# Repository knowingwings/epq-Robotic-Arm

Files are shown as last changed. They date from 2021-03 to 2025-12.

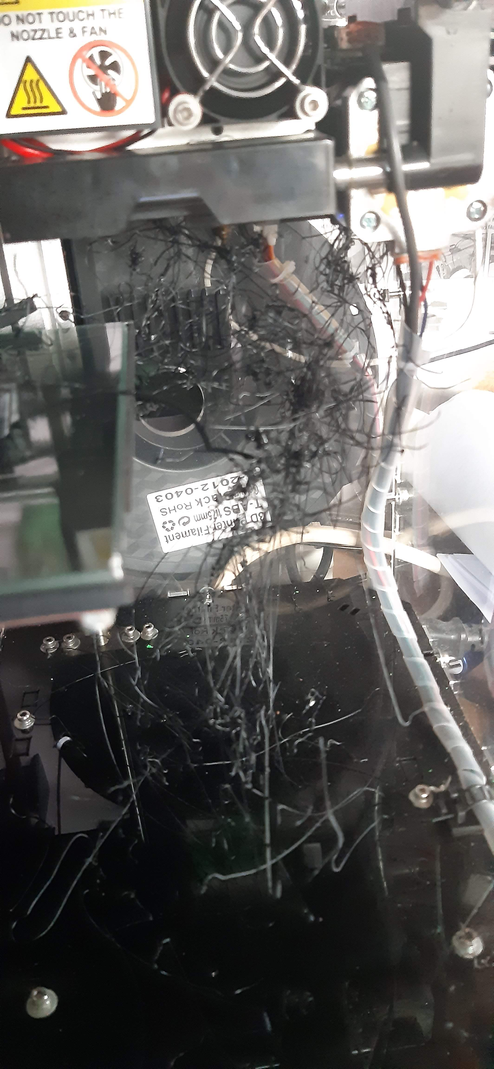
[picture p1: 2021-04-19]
Testing_Documentation/Testing_Evidence/20210409_082313.jpg

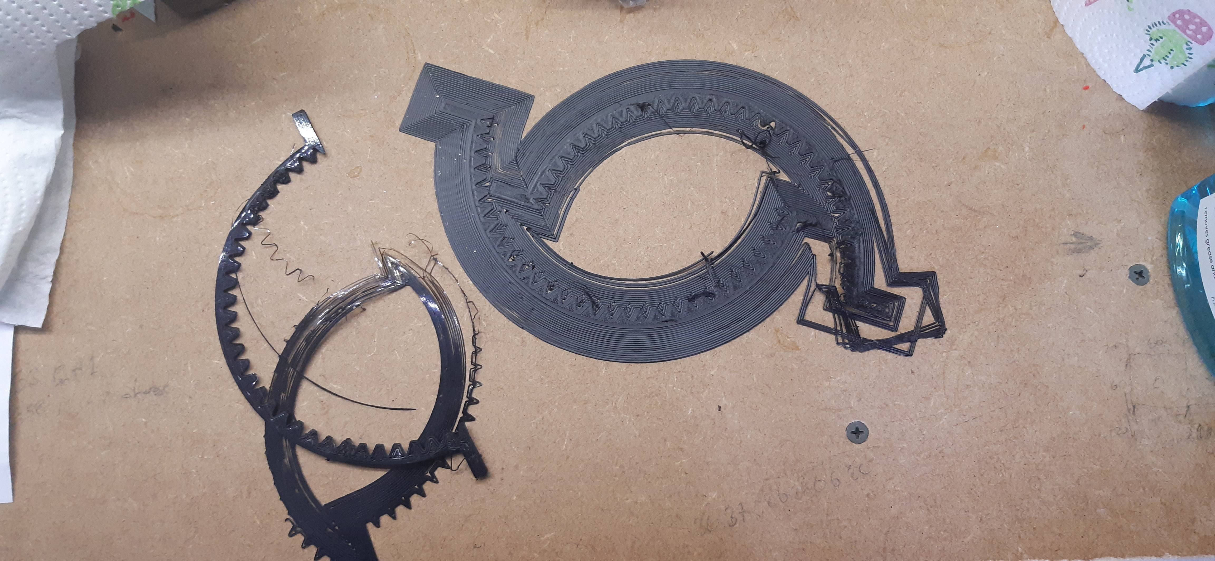
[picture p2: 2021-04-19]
Testing_Documentation/Testing_Evidence/20210409_155532.jpg

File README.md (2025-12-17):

# 6-DOF Robotic Arm with Custom Strain Wave Gearing

A-Level Extended Project Qualification (EPQ) - Grade: A*

## Project Overview

This project involved the complete design and manufacture of a 6 degree-of-freedom robotic manipulator from first principles. Conducted at Elizabeth College, the arm features custom-designed strain wave (harmonic drive) gearing for high torque density and backlash-free motion.

**Key achievements:**
- Full kinematic chain design with 6 DOF
- Custom strain wave gearboxes designed and 3D printed
- Four major design iterations (Mk1 through Mk4.2) refining the design
- Arduino-based motion control with serial communication
- Complete CAD modelling in Fusion 360
- Comprehensive research into industrial robotic arm design

**Project duration:** September 2020 - April 2022 (500 days actual vs 210 days planned)

**Institution:** Elizabeth College
**Candidate:** Thomas William Le Huray

## Technical Specifications

### Mechanical Design

**Degrees of Freedom:** 6 (base rotation, shoulder, elbow, wrist pitch, wrist roll, gripper)

**Actuation:** NEMA 17 stepper motors (17HS16-2004 and 17HS4401S models)

**Gear Reduction:** ~100:1 through custom strain wave gearing

**Payload Capacity:** <0.8 kg (designed for light manipulation tasks such as 3D printer print removal)

**Materials:**
- PLA (3D printed structural components)
- Recycled aluminium arm pieces (Mk1-Mk3, from scrapped screen soldering machine)
- Custom 3D printed components (Mk4)
- Steel hardware (fasteners, bearings)

### Harmonic Drive Design

One of the key innovations in this project was the design and manufacture of custom strain wave gearboxes inspired by industrial Harmonic Drive SE units:

**Design features:**
- Wave generator (elliptical input)
- Flexspline (flexible outer gear)
- Circular spline (rigid internal gear)
- Modified output design for 3D printing (uses rigid internal gear as output rather than flexspline)
- ~100:1 reduction ratio
- Zero backlash operation
- Compact form factor

**Design inspiration:**
- 3D Printed Life's harmonic drive designs
- Levi Janssen's timing belt-based harmonic drives
- Industrial Vika-350 robotic arm
- Chris Annin's AR4 open-source arm

**Iterations:** Multiple design revisions (v1 to v15) optimising:
- Tooth profile for load capacity
- Flexspline wall thickness for flexibility
- Material selection for durability (PLA)
- Assembly tolerances for 3D printing

## Design Evolution

### Mk1: Initial Proof-of-Concept
- Used recycled metal arm pieces from Offshore Electronics work experience
- Bespoke components for each joint
- Too complex to manufacture with 3D printing
- Identified need for component standardisation

### Mk2: Shared Components
- Increased number of shared components
- Lighter design than Mk1
- First functional harmonic drive prototypes
- Still too heavy for the motors and reducers

### Mk3: Further Weight Reduction
- Further increased shared components
- Improved harmonic drive design
- Isometric sketches preceded CAD work
- Lower axis drives proved too weak to lift the arm
- Metal arm components still too heavy

### Mk4: Complete Redesign (Final Version)
**Mk4.1:**
- Complete redesign from scratch
- All components 3D printed (no recycled metal)
- Initial version too large and cumbersome
- Some parts didn't work as intended

**Mk4.2 (Final):**
- Reduced size by 100mm
- Fixed mechanical issues from Mk4.1
- Well thought-out design incorporating lessons from all previous versions
- Culmination of improved CAD and 3D printing skills

## Control System

### Hardware
- **Microcontroller:** Arduino
- **Motors:** NEMA 17 stepper motors (17HS16-2004, 17HS4401S)
- **Motor Drivers:** A4988 stepper drivers
- **Control Interface:** Raspberry Pi (planned) for remote access via Python

### Software
- **Motor Control:** AccelStepper library for Arduino
- **Language:** C++ (Arduino), Python (Raspberry Pi interface planned)
- **Communication:** Serial communication protocol
  - Commands specify: axis, number of steps, direction
- **Interface:** Python script (via pySerial) for remote control

### Control Architecture
Arduino receives commands via serial input → Interprets axis and step commands → Controls stepper motors via AccelStepper → Enables remote access through Raspberry Pi

## Manufacturing Challenges

### 3D Printing Issues

**Original Printer (PrintRite Colido 2.0 Plus):**
- Stopped functioning correctly during Mk3 testing
- Resulted in failed prints and project delays

**Replacement Printer (Voxelab Aquila X2):**
- Ender 3 clone with additional features
- Successfully printed Axis 4, 5, and 6 of Mk4.1
- Developed heat break clogging issue
- Plastic melted in heat break causing repeated printer failures
- Unable to resolve despite multiple disassembly attempts
- Project pivoted to focus on CAD design refinement due to timeline constraints

## Research Foundation

Comprehensive research into:
- **Industrial Arms:** Vika-350, KUKA KR350
- **Open-Source Projects:** Annin AR4, Faze 4 Robotics Hand
- **Gear Reducers:** Harmonic drives, cycloidal drives, planetary gearboxes
- **Control Systems:** Inverse kinematics, stepper motor control
- **3D Printing:** Gear tooth design, support-free printing techniques

See Works Cited in documentation for complete bibliography.

## Project Management & Timeline

**Original Estimate:** 210 days
**Actual Duration:** 500 days
**Timeline Overrun:** 138%

**Key Learning:** Poor initial planning that didn't account for:
- Examination periods
- Holiday breaks
- General inability to work on project during school term
- Hardware failures (3D printer issues)

**Reflection:** More pessimistic timelines would have been more accurate. Future projects should account for realistic availability and potential setbacks.

## Repository Structure

```
epq-Robotic-Arm/
├── CAD-files/
│   ├── Harmonic Drive/        # Strain wave gearbox components
│   ├── Mk2+3/                 # Early prototype iterations
│   ├── Mk4/                   # Final design iteration (Mk4.1 and Mk4.2)
│   └── Test Components/       # Test pieces and prototypes
│
├── Program_Files/
│   ├── test_Files/            # Motor control tests
│   │   └── Arduino/           # Stepper motor test code (AccelStepper library)
│   └── (main control code)
│
├── Components_Files/          # Bill of materials, component specs
│
├── documentation/
│   ├── EPQ Report draft 2.docx    # Complete project report
│   ├── EPQ Gantt Chart.xlsx       # Project timeline (planned vs actual)
│   └── EPQ Shopping List.xlsx     # Component sourcing
│
└── Testing_Documentation/     # Test results and validation
```

## Results

**EPQ Grade:** A* (highest grade)

**Project Outcomes:**
- Functional 6-DOF robotic arm design (Mk4.2)
- Custom harmonic drive gearboxes that achieved zero backlash
- Complete documentation and testing methodology
- Well-developed CAD skills through iterative design process

**Intended Applications:**
- 3D printer print removal
- Light object manipulation
- Control software experimentation
- Educational demonstration of robotic principles

## Key Learnings

This project provided hands-on experience in:

**Mechanical Engineering:**
- Kinematic chain design
- Custom gear design (strain wave gearing)
- Load analysis and structural design
- Tolerance analysis for 3D printed assemblies
- Iterative prototyping methodology
- Design optimisation through multiple iterations

**Software Engineering:**
- Arduino programming in C++
- Real-time motor control
- Serial communication protocols
- Library integration (AccelStepper)

**Systems Integration:**
- Electromechanical system design
- Power distribution
- Motor driver configuration
- Assembly and calibration procedures

**Project Management:**
- Timeline estimation and planning
- Adapting to setbacks and hardware failures
- Resource management
- Documentation practices

## Skills Demonstrated

- **CAD Modelling:** Fusion 360 (complex assemblies, gear design)
- **3D Printing:** Iterative prototyping, troubleshooting print failures
- **Mechanical Design:** Kinematics, gearing, structural analysis
- **Embedded Programming:** Arduino, C++
- **Control Systems:** Stepper motor control, serial communication
- **Research:** Comprehensive literature review and evaluation
- **Problem-Solving:** Four major design iterations, adapting to constraints
- **Technical Writing:** Comprehensive project report and documentation

## Progression

This EPQ project was the foundation for my continued work in robotics:

**Academic Progression:**
- **2020-2022:** A-Level (Maths, Physics, Computer Science) - Elizabeth College
- **2022-2023:** BEng Mechatronics (First Class Honours) - University of Gloucestershire
- **2024-Present:** MSc Robotics and Autonomous Systems - University of Bath

**Research Development:**
- EPQ: Custom robotic arm with harmonic drives
- BEng: Decentralised control architectures for dual mobile manipulators
- MSc: Multi-robot coordination and distributed control systems

See my [GitHub profile](https://github.com/knowingwings) for current projects including:
- [Distributed Mobile Robots](https://github.com/knowingwings/distributed-mobile-robots) - ROS2 multi-robot coordination platform
- [Decentralised Mobile Manipulator](https://github.com/knowingwings/decentralized-mobile-manipulator) - GPU-accelerated coordination algorithms

## Files & Documentation

**Key Files:**
- `documentation/EPQ Report draft 2.docx` - Complete project report
- `documentation/EPQ Gantt Chart.xlsx` - Timeline (planned vs actual)
- `CAD-files/Mk4/` - Final design CAD files (Fusion 360)
- `CAD-files/Harmonic Drive/` - Strain wave gearbox designs (v1-v15)
- `Program_Files/test_Files/Arduino/` - Motor control test code

**Note:** This was one of my first major engineering projects completed at age 16-18. The code and documentation reflect my skills at A-Level. For more recent work, see my university projects and current research.

## Acknowledgements

- Elizabeth College for supervision and support
- Offshore Electronics for work experience and recycled components (Mk1-Mk3)
- Open-source community for inspiration (Annin Robotics, 3D Printed Life, Levi Janssen)

## Licence

This project was completed as part of A-Level coursework. Code and designs provided for educational purposes.

## Author

**Thomas William Le Huray**
- Completed: April 2022 (A-Level Year 13)
- Grade: A* EPQ
- Institution: Elizabeth College
- Current: MSc Robotics @ University of Bath

---

*This repository documents my first significant robotics project at age 16-18. Whilst the implementation reflects early-stage skills, the project demonstrates fundamental engineering problem-solving, iterative design methodology, and hands-on fabrication capabilities that have continued to develop through my degree programmes.*

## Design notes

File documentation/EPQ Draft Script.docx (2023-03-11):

EPQ Draft Script:

Title slide:

My epq is the design and manufacture of a robotic arm.

00 Contents:

In this presentation I’m going to take you through what my project was about; the research I did; my plan; prototypes mk1 – mk3; the actual prototyping; the final design; and the manufacturing of the arm.

Video Slide:

This is roughly the idea of what I wanted the arm to be like at the beginning and you will see the full evolution of my design through the presentation.

01 Overview:

I decided early in the process of brainstorming my EPQ that I wanted to make a robotic project. I had many ideas from a quadruped robot, like Spot from Boston Dynamics, to making my own drone. Eventually I landed on a robotic arm, the simplest of all my ideas. With that I had an overall goal and I needed to work out the details I decided that it needed upwards of 5 degrees of freedom, how much the arm can move around, and be able to lift about 0.8kg (800grams). With this I began my research.

02 Research:

There are many ways to find information about robotic applications, people’s personal blogs; forum posts; and of course, YouTube. As you can see from the chart most of my research came from YouTube, the algorithm obviously knowing me too well. Lots of my research was into 3D printed reducers and transmissions.

03 The Plan:

I originally planned for the project too only take me 5 and a half months: in reality it has taken me well over a year, with many breaks for exams, young enterprise, generally forgetting that I had to do the project. I documented what happened through a development journal, this ended up becoming incredibly long. At the end of April, I had a block out for mk1 and then put the project on hold for exams.

04 Mk1 – Mk3:

In June I picked the project back up after salvaging aluminium hinged pieces from a scrapped screen soldering machine, from my work experience at Offshore Electronics. Mk1 featured a mixture of different types of geared reducers, planetary gearboxes and harmonic drives. However, the arm contained many bespoke parts, and weighed far too much for it too lift itself. Mk2 was lighter and featured more common components to reduce the complexity of manufacturing. Even though there was many improvements from mk1 to mk2 there was still room for improvement as the arm was still very heavy and unable to meet the lifting goal I was aiming for. Mk3 improved on Mk2 by reducing the weight of the arm by roughly 10%, and featured component coverings that reduced the number of exposed parts. Now you might be wondering what a harmonic drive is.

05 How it works:

A harmonic drive is a type of reducers, they are also called Strain wave gearing. You might be wondering why the name harmonic drive, well that’s because it’s named after the company that manufactured the first series of strain wave gearing, from Germany called Harmonic Drive SE. On the right you can see my 3rd version of a harmonic drive with a good reduction for the size. Strain wave gearing works by rotating an elliptical plane that forces a flexible gear, called the flexspline, to mesh with a fixed internal gear. In an industry standard design, the flexspline is attached to the output of the reducer, however due to the nature of 3D printed materials this is not possible as the flexspline will crack and fracture. In a 3D printed design another non-flexible internal gear is placed on top and used as the output, this design is inspired by the work of both 3D printed life and Levi Janssen both people who appear often in my research.

06 Prototyping:

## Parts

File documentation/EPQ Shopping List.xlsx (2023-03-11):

Component | Pcs | Price 1pc | Price (in £) | Link | Weight (g) | Height (mm) | Length (mm) | Width (mm)
Nema 23 | 1 | $20.42 | 14.75 | https://www.omc-stepperonline.com/nema-23-bipolar-1-8deg-1-26nm-178-4oz-in-2-8a-2-5v-57x57x56mm-4-wires.html | 700 | 56 | 57 | 57
Nema 17 | 5 | $11.22 | 8.11 | https://www.omc-stepperonline.com/nema-17-bipolar-45ncm-64oz-in-2a-42x42x40mm-4-wires-w-1m-cable-and-connector.html | 310 | 40 | 42 | 42
Nema 16 | 0 | $14.60 | 10.55 | https://www.omc-stepperonline.com/sale.html/clearance-sale-nema-16-bipolar-0-9deg-25ncm-35-4oz-in-0-3a-12v-39x39x44mm-4-wires.html | 270 | 44 | 39 | 39
Black ABS | 3 | £21.59 | 21.59 | https://www.amazon.co.uk/AnKun-Printer-Filament-Dimensional-Accuracy/dp/B08DHTXHPX | 1000
Power Supply (350W) | 2 | $28.88 | 20.86 | https://www.omc-stepperonline.com/350w-24v-146a-115230v-switching-power-supply-stepper-motor-cnc-router-kits-s-350-24.html
Motor Drivers (17s, 23s) | 6 | $29.48 | 21.3 | https://www.omc-stepperonline.com/digital-stepper-driver-10-42a-20-50vdc-for-nema-17-23-24-stepper-motor-dm542t.html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
Motor Driver (16) | 0 | $24.66 | 17.82 | https://www.oyostepper.com/goods-820-Digital-Stepper-Driver-for-Nema-8-11-14-16-17-Stepper-Motor-03-22A-10-30VDC.html
Arduino Max | 1 | £13.99 | 13.99 | https://www.amazon.co.uk/ELEGOO-Controller-ATmega2560-ATMEGA16U2-Compatible/dp/B06XKMZ3T9
M3
 |  | Total (£): | 303.58

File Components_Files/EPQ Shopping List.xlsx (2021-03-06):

Component | Pcs | Price 1pc | Price (in £) | Link | Weight (g) | Height (mm) | Length (mm) | Width (mm) | ordered
Nema 23 | 1 | $20.42 | 14.75 | https://www.omc-stepperonline.com/nema-23-bipolar-1-8deg-1-26nm-178-4oz-in-2-8a-2-5v-57x57x56mm-4-wires.html | 700 | 56 | 57 | 57 | https://www.amazon.co.uk/gp/product/B086MT1M9M/ref=ppx_yo_dt_b_asin_title_o02_s00?ie=UTF8&psc=1
Nema 17 | 5 | $11.22 | 8.11 | https://www.omc-stepperonline.com/nema-17-bipolar-45ncm-64oz-in-2a-42x42x40mm-4-wires-w-1m-cable-and-connector.html | 310 | 40 | 42 | 42 | https://www.amazon.co.uk/gp/product/B07FKH52S5/ref=ppx_yo_dt_b_asin_title_o01_s00?ie=UTF8&psc=1
Nema 16 | 0 | $14.60 | 10.55 | https://www.omc-stepperonline.com/sale.html/clearance-sale-nema-16-bipolar-0-9deg-25ncm-35-4oz-in-0-3a-12v-39x39x44mm-4-wires.html | 270 | 44 | 39 | 39
Black ABS | 3 | £21.59 | 21.59 | https://www.amazon.co.uk/AnKun-Printer-Filament-Dimensional-Accuracy/dp/B08DHTXHPX | 1000 |  |  |  | https://www.amazon.co.uk/gp/product/B08DHTXHPX/ref=ppx_yo_dt_b_asin_title_o00_s00?ie=UTF8&psc=1
Power Supply (350W) | 2 | $28.88 | 20.86 | https://www.omc-stepperonline.com/350w-24v-146a-115230v-switching-power-supply-stepper-motor-cnc-router-kits-s-350-24.html |  |  |  |  | https://www.amazon.co.uk/gp/product/B08GKVVZTF/ref=ppx_yo_dt_b_asin_title_o00_s00?ie=UTF8&psc=1
Motor Drivers (17s, 23s) | 6 | $29.48 | 21.3 | https://www.omc-stepperonline.com/digital-stepper-driver-10-42a-20-50vdc-for-nema-17-23-24-stepper-motor-dm542t.html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 |  |  |  |  | https://www.amazon.co.uk/gp/product/B08GCFNQF2/ref=ppx_yo_dt_b_asin_title_o00_s00?ie=UTF8&psc=1
Motor Driver (16) | 0 | $24.66 | 17.82 | https://www.oyostepper.com/goods-820-Digital-Stepper-Driver-for-Nema-8-11-14-16-17-Stepper-Motor-03-22A-10-30VDC.html
Arduino Max | 1 | £13.99 | 13.99 | https://www.amazon.co.uk/ELEGOO-Controller-ATmega2560-ATMEGA16U2-Compatible/dp/B06XKMZ3T9 |  |  |  |  | https://www.amazon.co.uk/gp/product/B06XKMZ3T9/ref=ppx_yo_dt_b_asin_title_o00_s00?ie=UTF8&psc=1
M3
 |  | Total (£): | 303.58

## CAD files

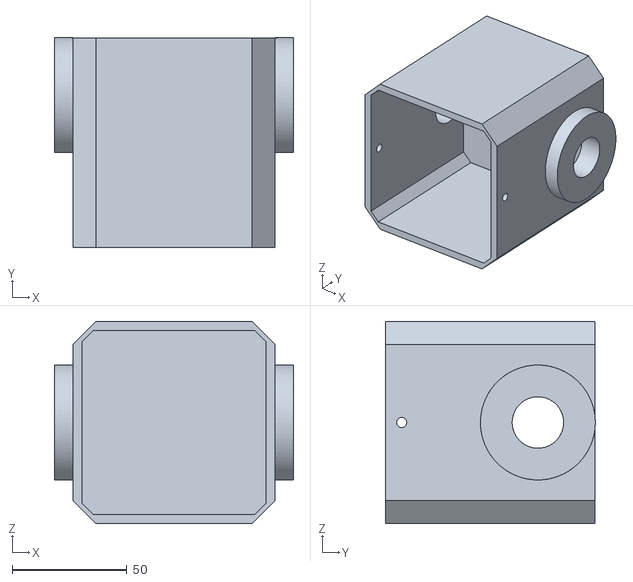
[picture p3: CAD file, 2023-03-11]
CAD-files/A6v2 Shell v3.stl
104.0 x 91.2 x 88.0

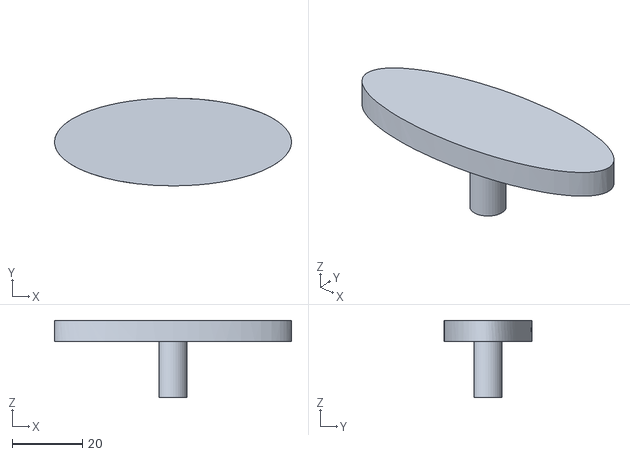
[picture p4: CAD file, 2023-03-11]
CAD-files/Harmonic Drive/Test/HD_Test-WG.stl
67.5 x 25.0 x 22.0

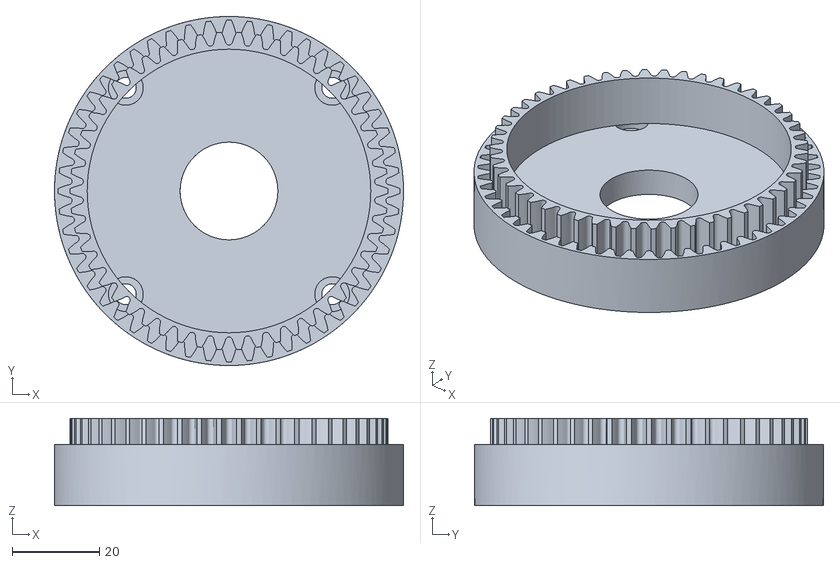
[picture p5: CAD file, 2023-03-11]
CAD-files/Mk2+3/N23 Harmonic Drive Rev3 v2.stl
80.0 x 80.0 x 20.0

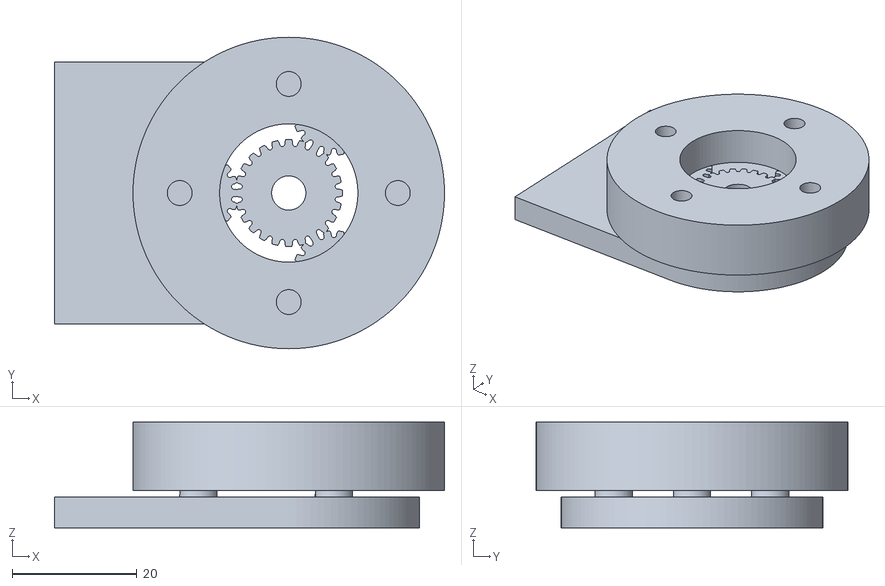
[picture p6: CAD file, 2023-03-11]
CAD-files/Mk4/EEPGB-2.0.stl
62.6 x 50.0 x 17.0

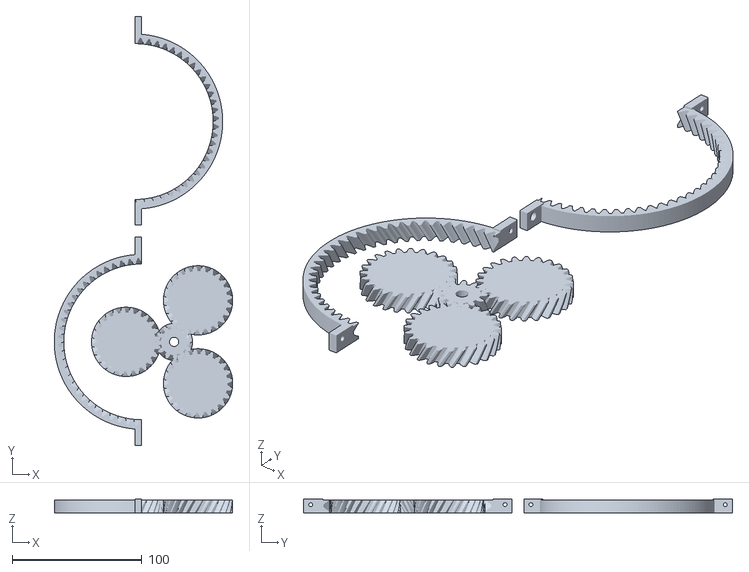
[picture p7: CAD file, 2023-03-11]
CAD-files/Test Components/Gearboxes/helical planetary gearbox23_ test v2 split.stl
137.7 x 331.1 x 11.0

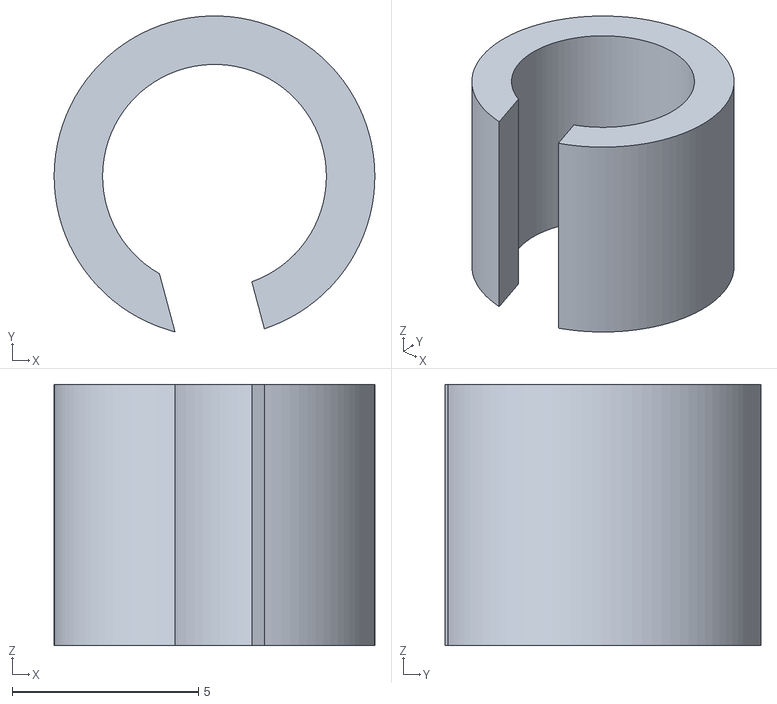
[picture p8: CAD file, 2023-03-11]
CAD-files/5-8mm Converter v2.stl
8.60 x 8.47 x 7.00

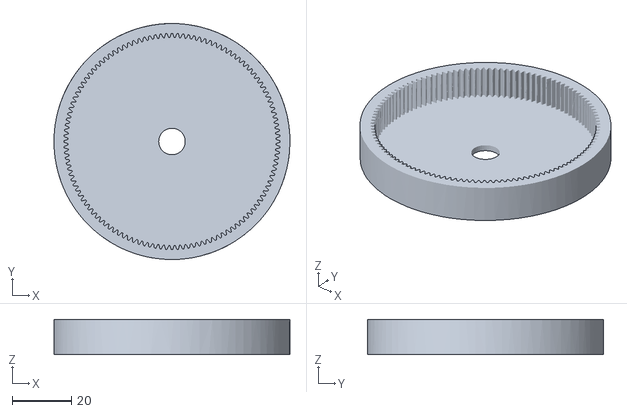
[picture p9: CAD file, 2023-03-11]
CAD-files/Harmonic Drive/Test/HD_Test-LR.stl
80.0 x 80.0 x 12.0

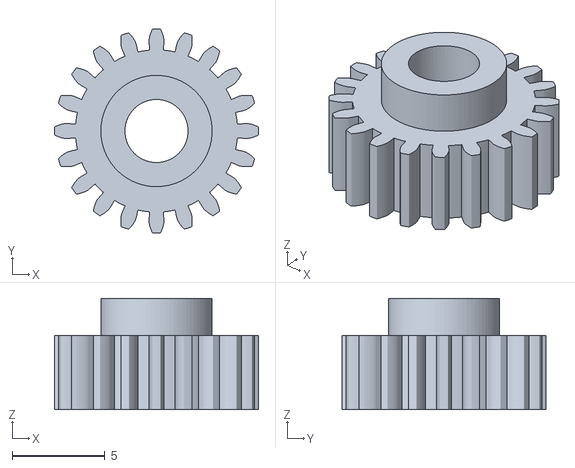
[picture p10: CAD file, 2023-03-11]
CAD-files/A6EE_Spur v2.stl
11.0 x 11.0 x 6.00

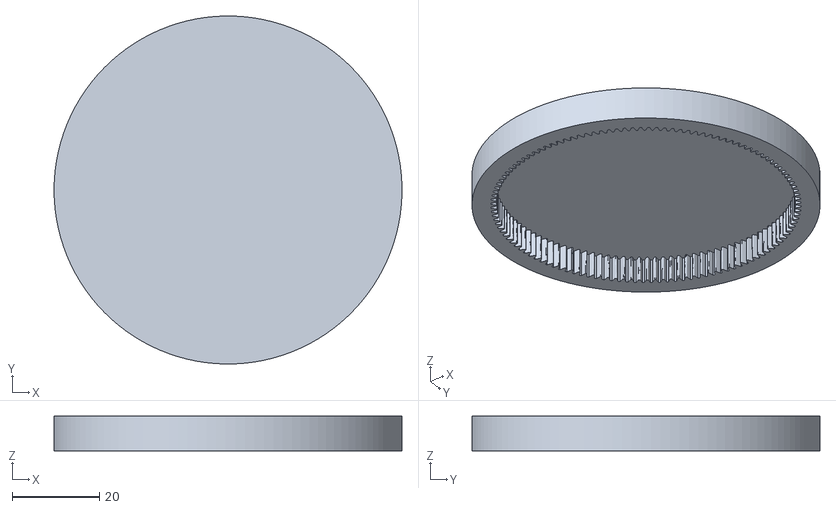
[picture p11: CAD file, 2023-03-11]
CAD-files/Harmonic Drive/Test/HD_Test-OR.stl
80.0 x 80.0 x 8.00

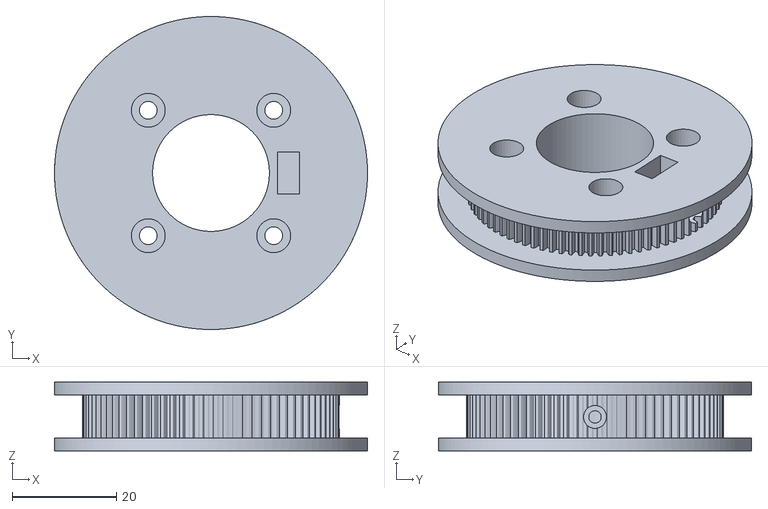
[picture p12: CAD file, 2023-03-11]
CAD-files/Mk4/Axis5 Pulley v5.stl
60.0 x 60.0 x 13.2

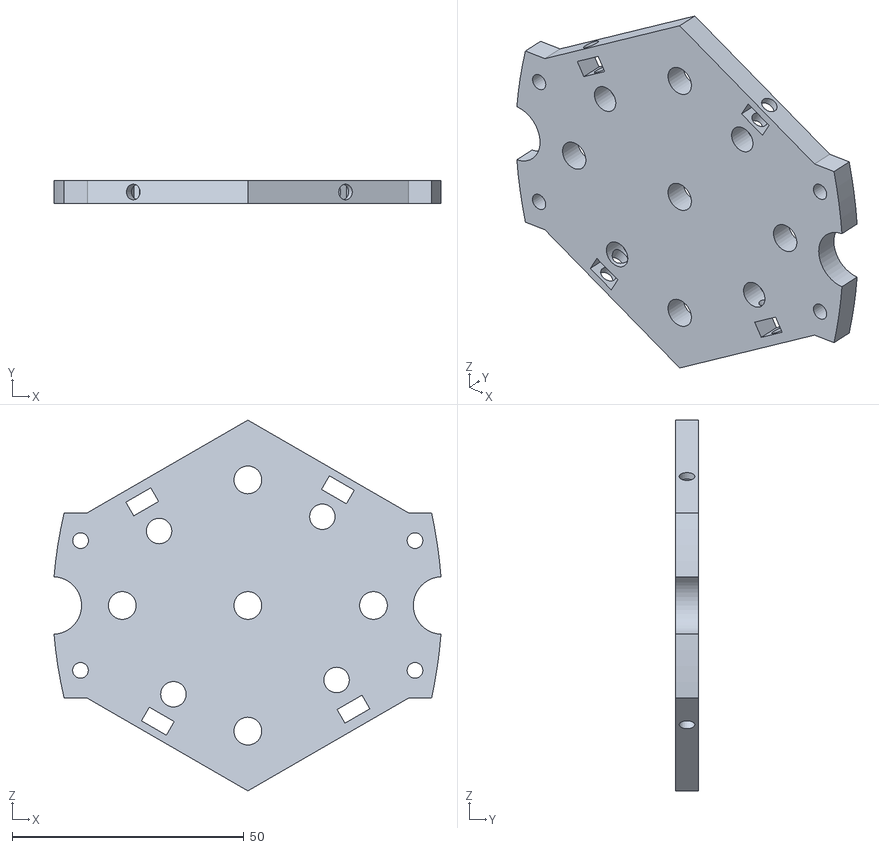
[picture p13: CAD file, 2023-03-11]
CAD-files/mk4v1/A4 Mid Support Structure v7.stl
83.5 x 5.00 x 80.0

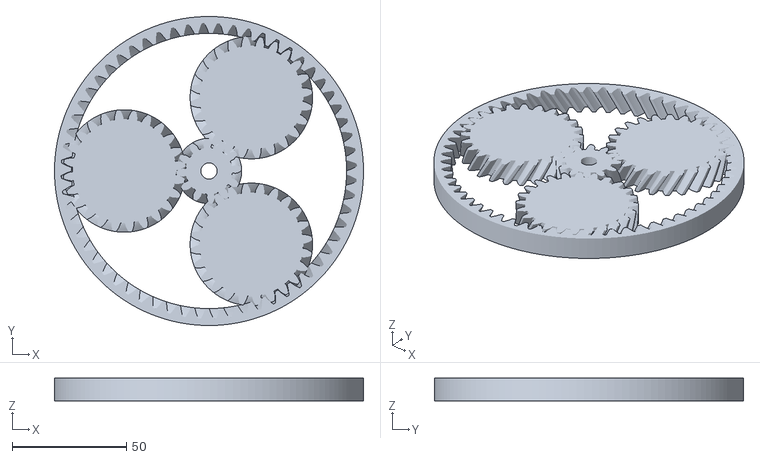
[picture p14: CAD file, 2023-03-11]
CAD-files/Test Components/Gearboxes/Helical Planetary 23_test.stl
135.0 x 135.0 x 10.0

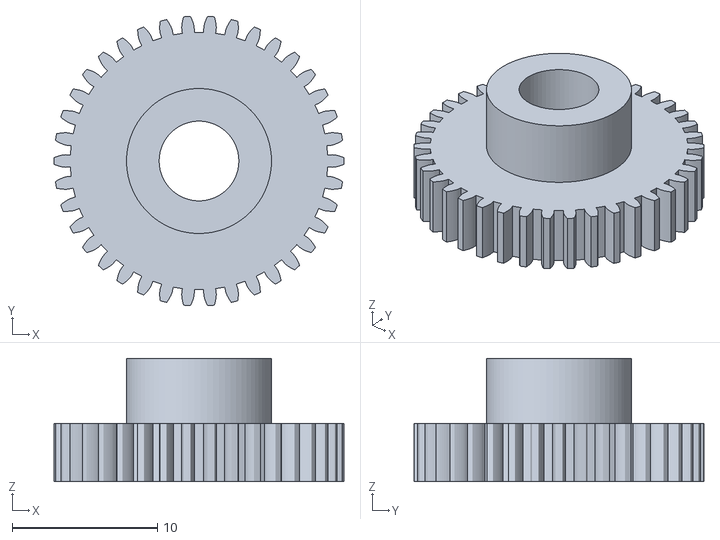
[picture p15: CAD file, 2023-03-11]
CAD-files/A6EE_Spur_Centre v5.stl
20.0 x 20.0 x 8.50

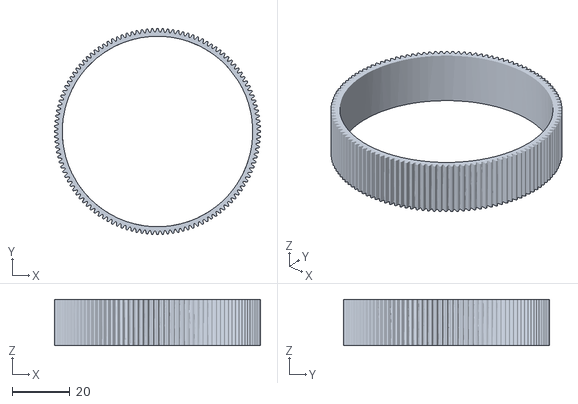
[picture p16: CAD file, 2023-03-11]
CAD-files/Harmonic Drive/Test/HD_Test-FS.stl
71.2 x 71.2 x 16.0

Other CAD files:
CAD-files/Mk2+3/Upper Shoulder v3.stl
CAD-files/Mk4/EEPGB-1.6.stl
CAD-files/mk4v1/A6S-1.1.stl
CAD-files/Test Components/Gearboxes/Planetary Gearbox 23_TEST v1.stl
CAD-files/Mk2+3/Elbow Spacer v5.stl
CAD-files/Mk2+3/Elbow Spacer v7.stl
CAD-files/Mk2+3/Elbow Spacer v9.stl
CAD-files/Mk2+3/Harmonic Drive N23 v1.stl
CAD-files/Mk2+3/Harmonic Drive N23 v11.stl
CAD-files/Mk2+3/Harmonic Drive N23 v13.stl
CAD-files/Mk2+3/Harmonic Drive N23 v15.stl
CAD-files/Mk2+3/Harmonic Drive N23 v2.stl
CAD-files/Mk2+3/Harmonic Drive N23 v3.stl
CAD-files/Mk2+3/Harmonic Drive N23 v5.stl
CAD-files/Mk2+3/Harmonic Drive N23 v8.stl
CAD-files/Mk2+3/N17 Forearm Bracket (Twist Axis) v4.stl
CAD-files/Mk2+3/N17 Forearm Bracket (Twist Axis) v6.stl
CAD-files/Mk2+3/N17 Forearm Bracket (Twist Axis) v7.stl
CAD-files/Mk2+3/N17 Forearm Twist axis Mount v1.stl
CAD-files/Mk2+3/N17 Joint Bracket v13.stl
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

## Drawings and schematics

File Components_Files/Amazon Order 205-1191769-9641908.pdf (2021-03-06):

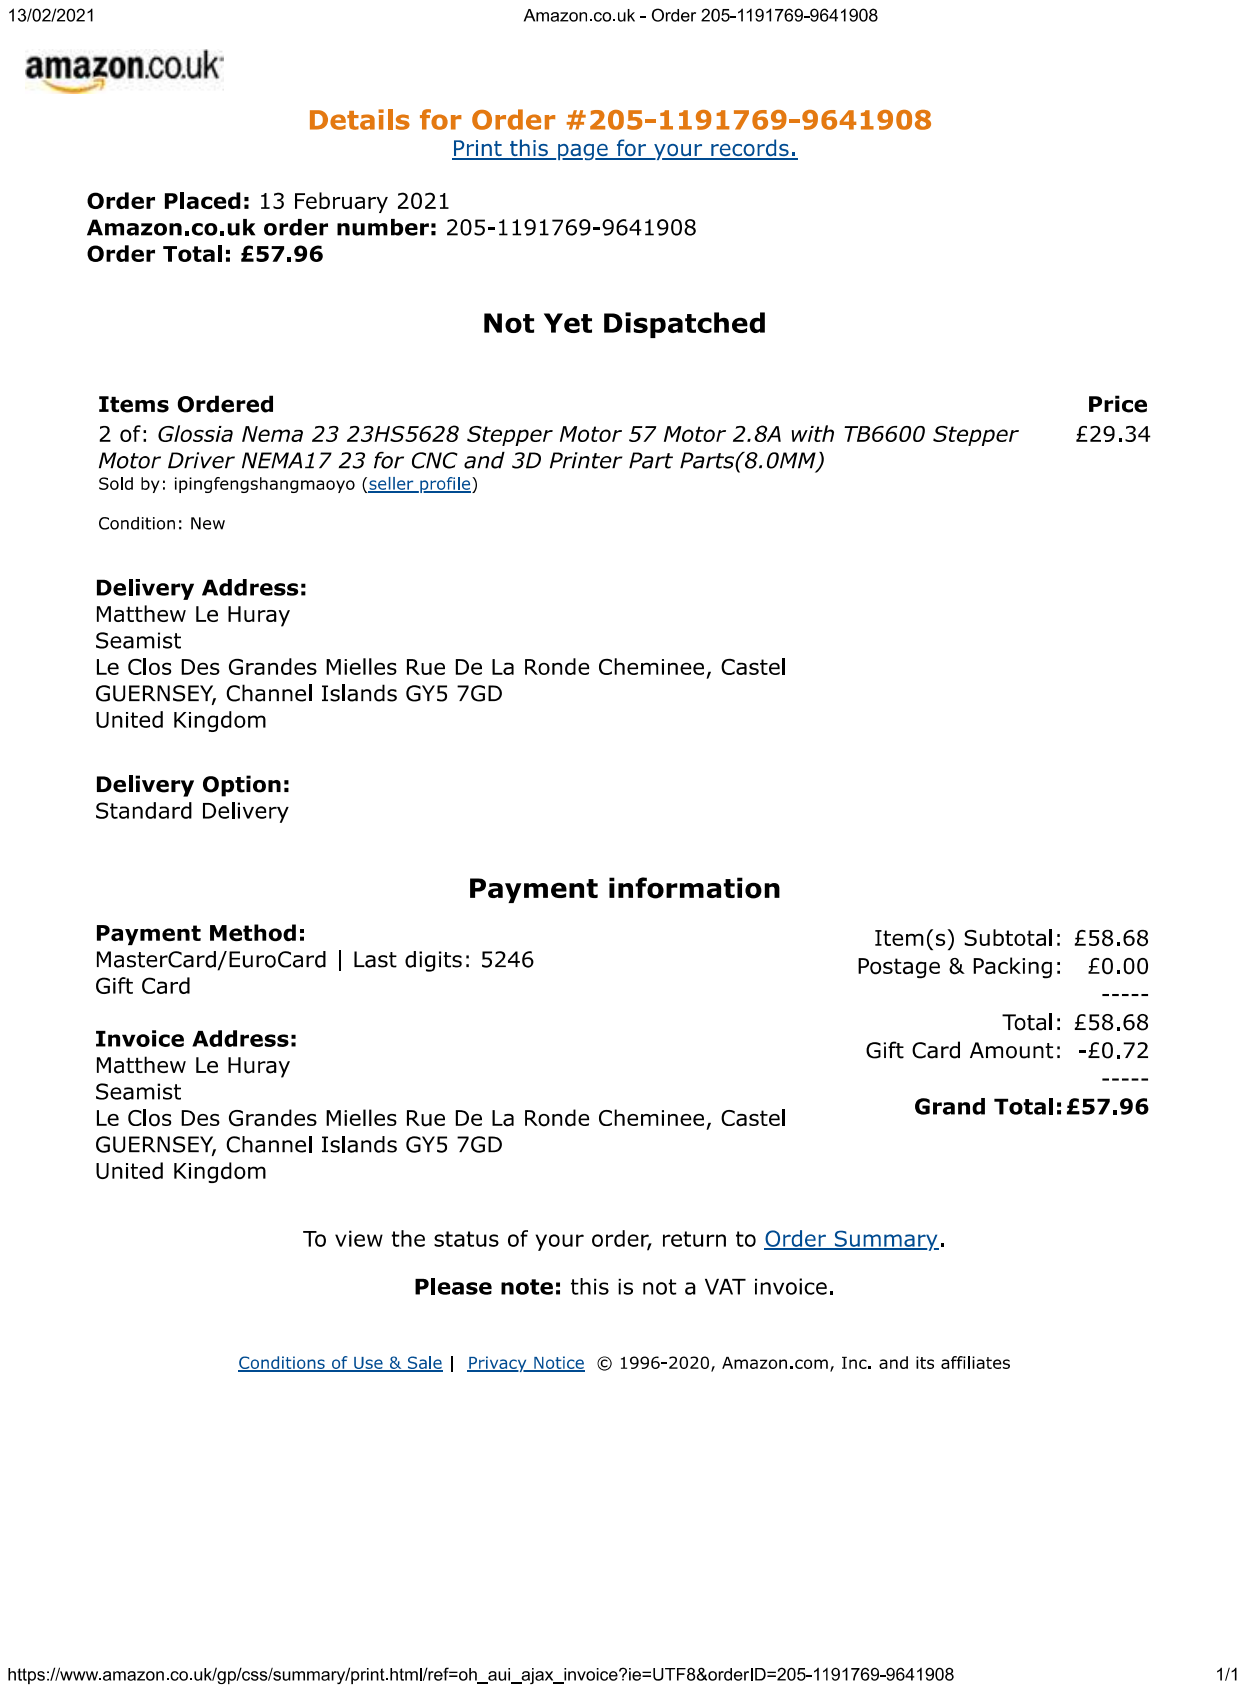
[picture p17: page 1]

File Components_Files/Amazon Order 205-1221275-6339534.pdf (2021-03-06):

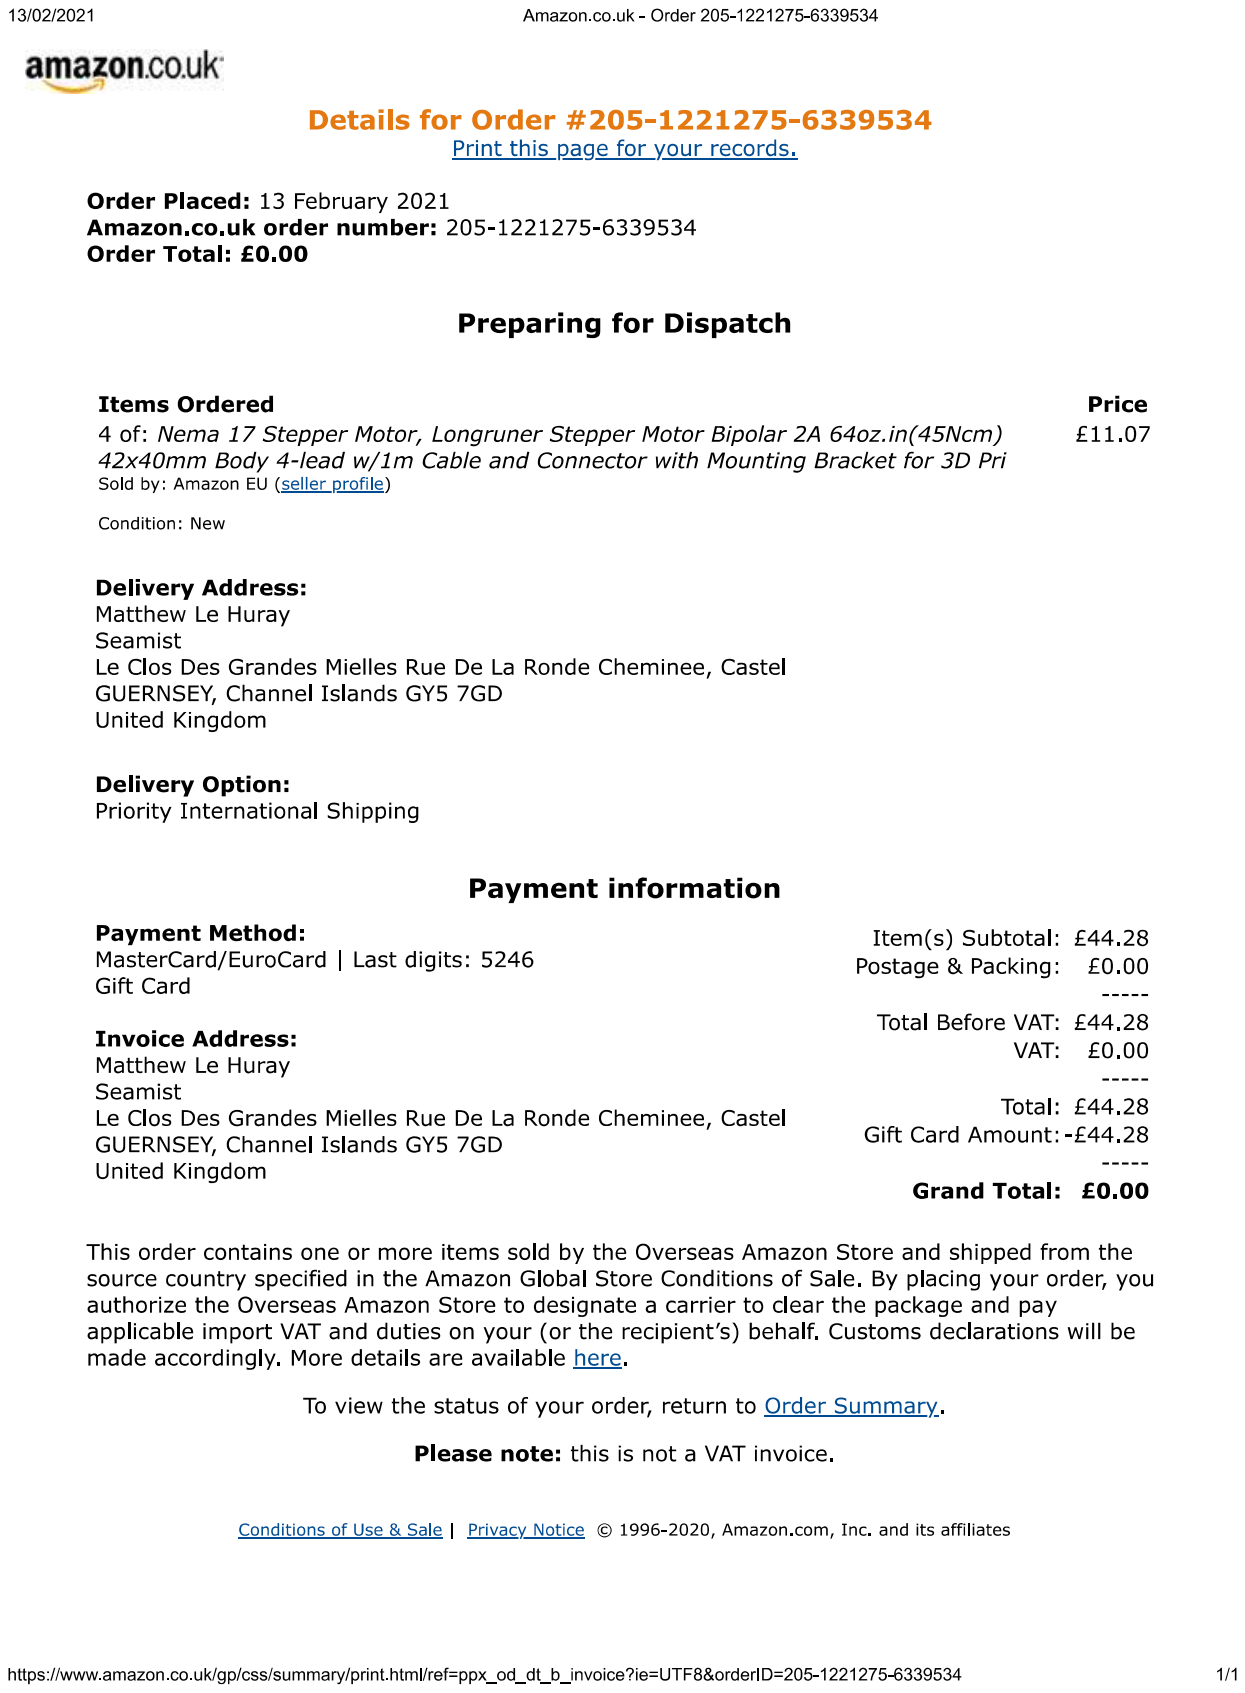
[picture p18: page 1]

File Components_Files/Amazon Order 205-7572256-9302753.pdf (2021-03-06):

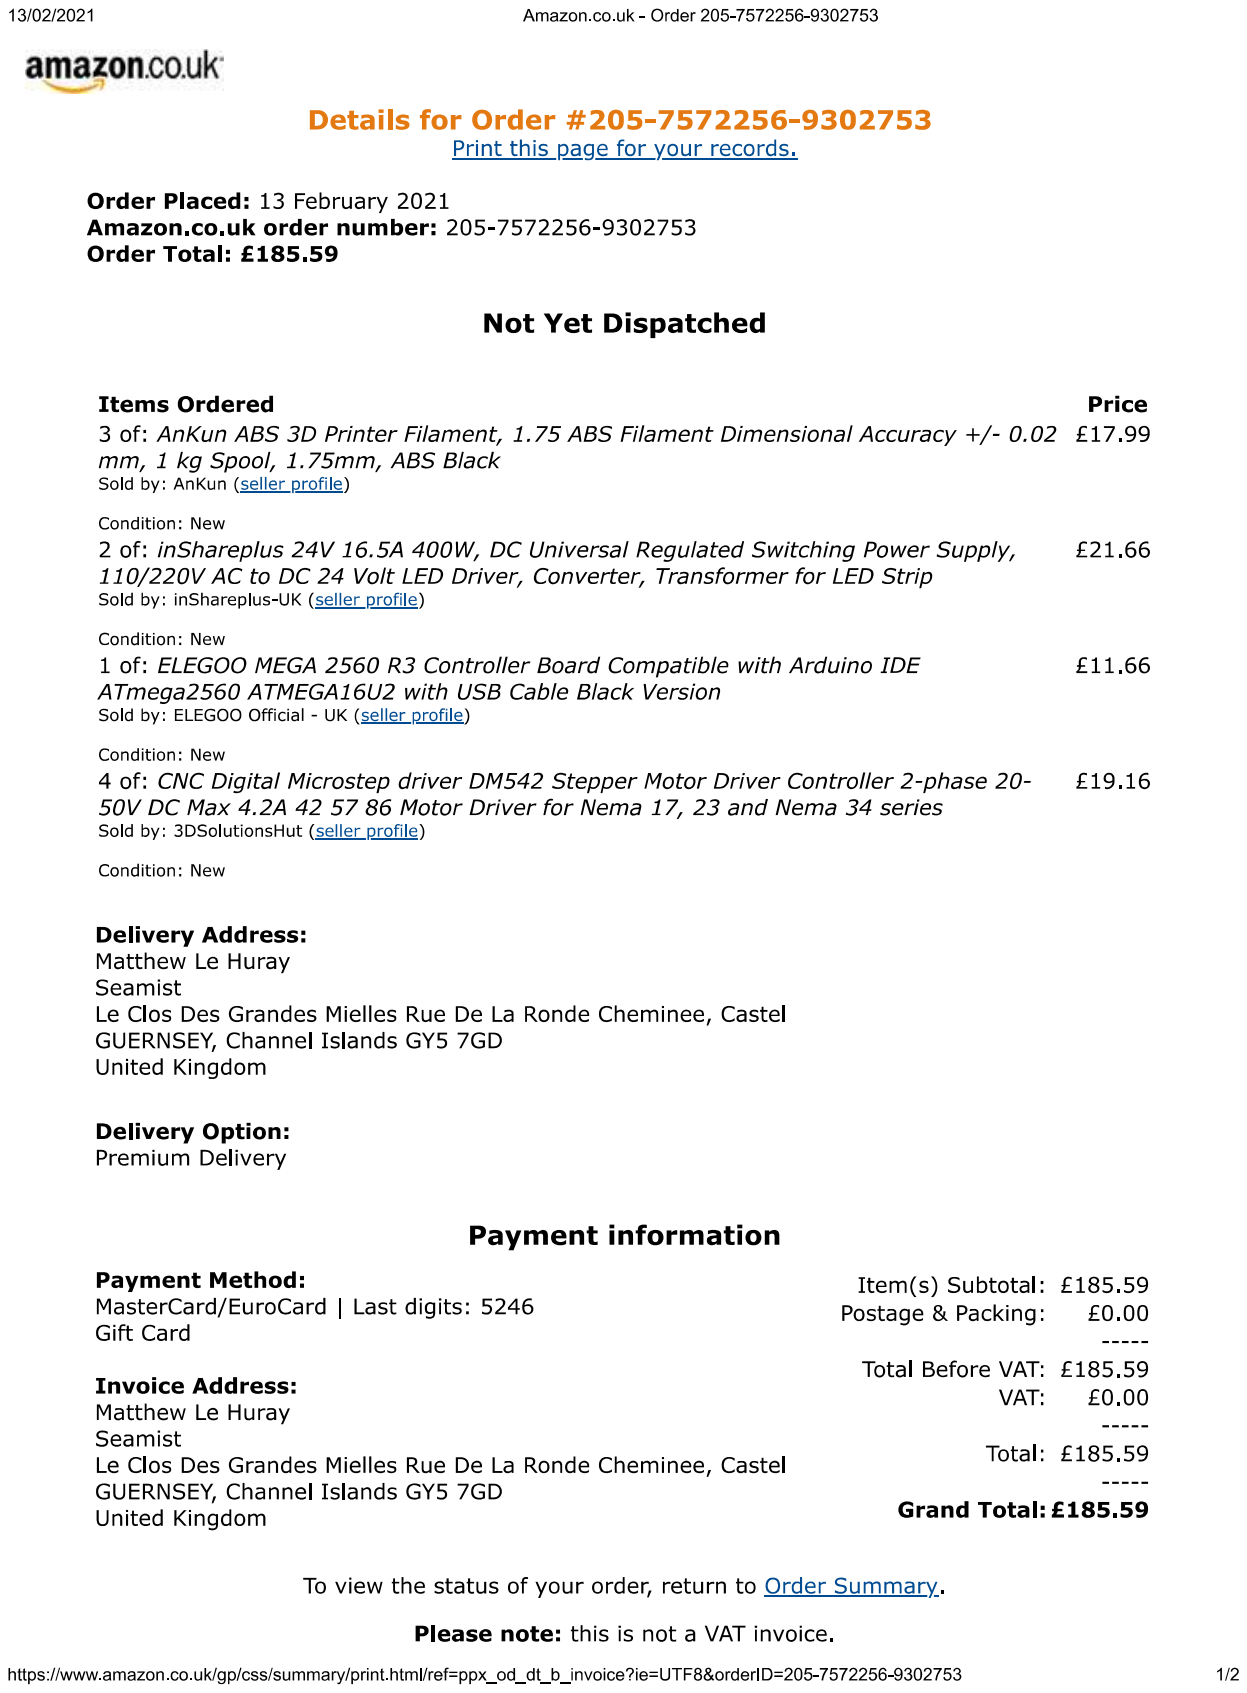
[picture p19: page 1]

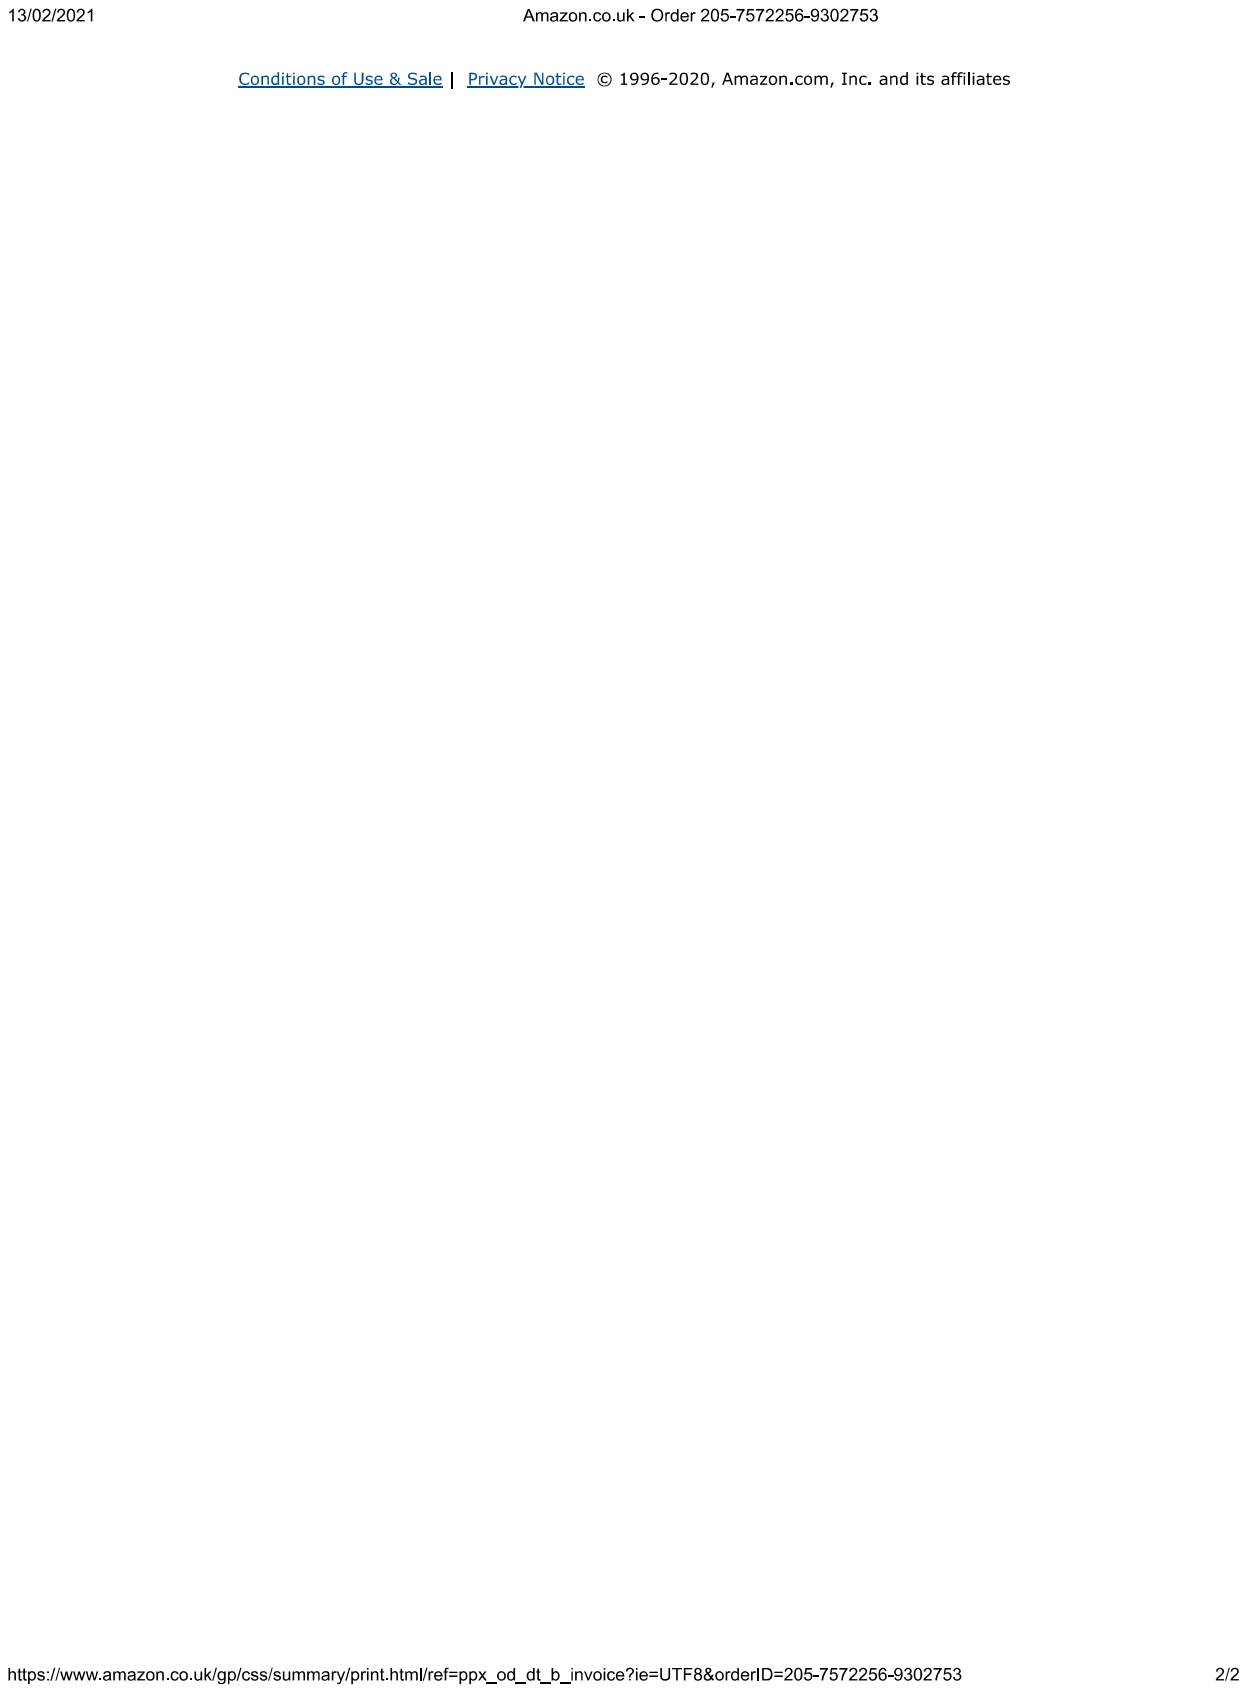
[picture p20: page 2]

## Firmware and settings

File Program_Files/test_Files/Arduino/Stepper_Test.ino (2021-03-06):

int stepPin = 5;
int dirPin = 6;
int enblPin = 7;

void setup() {
pinMode (stepPin, OUTPUT);
pinMode (dirPin, OUTPUT);
pinMode (enblPin, OUTPUT);
digitalWrite(stepPin, LOW);
digitalWrite(dirPin, LOW);
digitalWrite(enblPin, HIGH);
}

void loop() {
for(int x=0; x<1600; x++){
digitalWrite(stepPin, HIGH);
delayMicroseconds(100);
digitalWrite(stepPin, LOW);
delayMicroseconds(100);
}
digitalWrite(enblPin, LOW);
exit(0);
}

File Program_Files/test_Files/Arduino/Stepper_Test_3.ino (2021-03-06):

int pulPin = 10;
int dirPin = 11;
int enblPin = 12;
int ledPin = 13;

int loops = 0;

void setup() {
  // put your setup code here, to run once:
  pinMode(pulPin, OUTPUT);
  pinMode(dirPin, OUTPUT);
  pinMode(enblPin, OUTPUT);
  pinMode(ledPin, OUTPUT);

  digitalWrite(pulPin, LOW);
  digitalWrite(ledPin, LOW);
  digitalWrite(enblPin, LOW);
  digitalWrite(dirPin, LOW);

  Serial.begin(9600);
  Serial.println("init");

  digitalWrite(enblPin, HIGH);
  delay(100);
  digitalWrite(enblPin, LOW);
}
void stepper17_1() {
  digitalWrite(pulPin, HIGH);
  digitalWrite(ledPin, HIGH);
  digitalWrite(pulPin, LOW);
  digitalWrite(ledPin, LOW);

}
void loop() {
  // put your main code here, to run repeatedly: 
  stepper17_1();
  delay(0.5);
}

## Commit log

2021-03-06 Rename stepper control test.py to test_Files/Python/stepper control test.py
2021-03-06 Add Components List files
    [EPQ Shopping List.xlsx]
2021-03-06 Moved Component Files into a Folder
    [EPQ Shopping List.xlsx]
2021-03-06 quit button pos moddified
    Moved the quit button to side right not side down
2023-03-11 Added all EPQ documentation
    [EPQ Gantt Chart.xlsx, EPQ Shopping List.xlsx]
2023-03-11 Create CAD files dir
2023-03-11 Added ecported CAD files
    [12mm Structural Support v3.stl, 12mm Structural Support v4.stl, 5-8mm Converter v1.stl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]
2025-12-17 Improve documentation and add .gitignore
    - Replace basic README with comprehensive project overview
    - Document technical specifications and design iterations
    - Highlight custom harmonic drive gearbox design
    - Add context about project progression to current work
    - Include .gitignore for CAD and development files
    - Position as foundational early project (age 17-18)
    Updates professional presentation while being honest about the project timeline and skill level at the time.
2025-12-17 Update README with accurate details from EPQ report
    - Add complete project details from actual EPQ report
    - Include all four design iterations (Mk1-Mk4.2)
    - Document manufacturing challenges (printer failures)
    - Add timeline details (500 days vs 210 planned, 138% overrun)
    - Include proper motor specifications (NEMA 17 models)
    - Document control system architecture
    - Add research foundation and acknowledgements
    - Write in British English (modelling, optimising, etc.)
    - Specify Elizabeth College as institution
    - Add detailed harmonic drive design information
    - Include project management learnings
    Significantly more detailed and accurate than previous version.
